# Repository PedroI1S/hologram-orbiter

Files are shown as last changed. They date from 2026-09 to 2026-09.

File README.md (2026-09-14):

# Hologram Orbiter

Display por persistência de visão com três painéis de LEDs. Ponto de projeto:
raio médio 100 mm, 1800 RPM, 29 LEDs por painel e 180 colunas angulares.
A cinemática prevê 90 passagens por segundo; desempenho óptico ainda depende de firmware e ensaio.

**Versão vigente: v3.0, revisão local 3.0.5 de 14/09/2026.**

## Estado

**Não liberado para girar nem para a fabricação definitiva dos painéis.**
A revisão corrigiu a memória de flexão, as contas de partida e energia, os
procedimentos de instrumentação, a parametrização das folgas e as falhas do build.
O buck e suas guias foram recuados radialmente 1,2 mm para eliminar a colisão
com a aranha; o novo teste verifica os envelopes contra a malha final.

A revisão 3.0.5 remove a saliência dos braços dentro da baia e desobstrui
as três entradas de fios. Os critérios geométricos passam a verificar
também essas regiões na malha final.

A seção do painel tem Iyy = **589,8846 mm⁴**, abaixo dos 910 usados antes.
O modelo uniforme dá **3,83–7,74 mm** de deflexão com 44,5 g; no teto de aceite
45 g, chega a **7,83 mm** e ~29,1 MPa. Esses resultados corrigem a aritmética,
mas exigem fechar a transferência de carga, as propriedades FDM e a fluência.

Os relatórios automáticos são a referência da execução atual:

- [Aceitação geométrica](Hologram_Orbiter_v3_0/reports/ACEITACAO.md).
- [Validação e valores atuais](Hologram_Orbiter_v3_0/reports/RELATORIO_VALIDACAO.md).
- [Cálculos reproduzíveis](Hologram_Orbiter_v3_0/reports/FISICA.json).
- [Revisão completa](revisoes/2026-09-08-REVISAO-COMPLETA.md) e [correções aplicadas](revisoes/2026-09-08-CORRECOES-APLICADAS.md).

Aprovação geométrica não substitui os bloqueadores físicos. Massas de catálogo,
chicotes, bateria, ferragens e contrapesos devem ser reconciliados na pesagem real;
o subtotal CAD não comprova a margem até 280 g.

## Números de projeto

| Grandeza | Valor e condição |
|---|---|
| Rotação / velocidade angular | 1800 RPM / 188,496 rad/s |
| Motor / acionamento | A2212 920KV / ESC LittleBee Spring 20A |
| Corrente de regime prevista | 4,95 A de fase; ~16,63 W / 2,38 A na fonte de 7 V, com eficiência ESC assumida de 95% |
| Temperatura prevista | ~46,4 °C, sob as hipóteses térmicas; limite de aceite <55 °C |
| Partida nominal | rampa de RPM ≥12 s; ~7,30 A de fase / 4,02 A na fonte; medir aceleração real |
| Esticada a 2000 RPM | ~6,11 A / 56,3 °C; não liberada |
| Carga radial de referência | 158,1 N por painel de 44,5 g; ~159,9 N a 45 g |
| Energia de projeto | ~27,5 J para J=1,55 g·m², hipótese conservadora não medida |
| Painel solto | ~7,9 J e 18,9 m/s na referência de 44,5 g / r=100 mm |
| Desbalanceamento de referência | 8,4 g·mm usando 252 g; recalcular com a massa final e medir em dois planos |

## Documentos

| Uso | Arquivo |
|---|---|
| Cotas e memória de cálculo | [01 — Especificação](01-ESPECIFICACAO-CAD-v3.0.md) |
| Fases e portões | [02 — Plano de projeto](02-PLANO-DE-PROJETO-v3.0.md) |
| Componentes e instrumentos | [03 — Lista de componentes](03-LISTA-DE-COMPONENTES-v3.0.md) |
| Critérios físicos de aceite | [04 — Plano de ensaios](04-PLANO-DE-ENSAIOS-v3.0.md) |
| Eletrônica e firmware planejado | [05 — Esquema elétrico](05-ESQUEMA-ELETRICO-v3.0.md) |
| O que ainda falta | [06 — Pendências](06-PENDENCIAS-ABERTAS-v3.0.md) |
| Medições e premissas | [07 — Glossário](07-GLOSSARIO-E-PREMISSAS.md) |
| CAD, STL e montagem | [Pacote CAD](Hologram_Orbiter_v3_0/README.md) |

Parâmetros do CAD governam cotas, a especificação governa requisitos e o plano
de ensaios governa aceite físico. Divergências devem ser corrigidas; não se deve
escolher o valor que favorece a aprovação. O legado permanece arquivado e as
revisões históricas descrevem os resultados da data indicada.

Sentido de giro: anti-horário visto de cima; bordo de ataque em +y local.
Balança de 0,01 g, contenção e operação remota são requisitos do ensaio.

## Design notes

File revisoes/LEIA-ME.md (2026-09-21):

# Revisões

Revisões independentes do pacote v3.0, arquivadas por data. Cada uma é um
registro do estado do projeto num dia, com o que foi verificado e como.
Propostas datadas que aguardam decisão também ficam aqui, sob a mesma regra.

**Estes documentos não mandam em cota nem em requisito.** A hierarquia de
autoridade do [`../README.md`](../README.md) continua valendo: o arquivo de
parâmetros do CAD manda em cota, a especificação em requisito, o plano de
ensaios em critério de aceite e o glossário no que foi medido. Uma revisão
aponta divergências; quem as fecha são aqueles arquivos.

O que **falta** está sempre em
[`../06-PENDENCIAS-ABERTAS-v3.0.md`](../06-PENDENCIAS-ABERTAS-v3.0.md), não
aqui.

## Conteúdo

| Arquivo | Escopo | Estado |
|---|---|---|
| [`2026-09-21-PROPOSTA-SPI-QUAD.md`](2026-09-21-PROPOSTA-SPI-QUAD.md) | dados das três fitas: cadeia do 05 ou SPI quad, com ensaio de bancada | proposta, não adotada; decisão na 06 C10 |
| [`2026-09-14-CORRECAO-RAIZES-E-FIACAO.md`](2026-09-14-CORRECAO-RAIZES-E-FIACAO.md) | saliências internas e entradas de fios da aranha, revisão CAD 3.0.5 | corrigidas; sondagem da malha e regressão com os defeitos antigos |
| [`2026-09-03-REVISAO-DAS-RATIFICACOES.md`](2026-09-03-REVISAO-DAS-RATIFICACOES.md) | pacote na revisão de CAD 3.0.3, depois das ratificações B'3, C2 e C9 | aplicada; o que sobrou está na §7 |

A revisão independente anterior, de 03/09/2026, circulou como documento 08
solto e foi incorporada à lista de pendências, com a tabela de disposição dos
30 achados no fim daquele arquivo. Ela não está aqui.

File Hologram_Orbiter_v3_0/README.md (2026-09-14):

# Hologram Orbiter v3.0 — pacote CAD, revisão 3.0.5

**PROVISÓRIO — operação e fabricação definitiva dos painéis não liberadas.**
Revisão local de 14/09/2026. Os cupons continuam úteis para calibração; lote
estrutural depende de fechar seção resistente, transferência de carga, ABS FDM,
fluência, massas/chicotes reais e os bloqueadores do plano de ensaios.

A seção da lâmina é integrada desde os parâmetros e conferida em três cortes
na malha. A folga radial usa a carga do teto de 45 g, com deflexão estimada
máxima de 7,83 mm. Nenhuma alteração de perfil estrutural foi adotada sem validação.
O buck permanece a 140°; o envelope e as guias recuaram 1,2 mm radialmente,
com wall_gap=1,5 mm, para livrar a raiz da aranha.

As raízes dos braços começam em r=39 mm, sem a saliência interna na baia.
O corte de entrada dos fios começa em x local=37 mm e atravessa toda a parede.
A prévia `aranha_entrada_fios.png` mostra o detalhe corrigido; dois critérios
novos sondam as raízes e as janelas na malha final dos três braços.

## Arquivos

| Uso | Arquivo | Qtd |
|---|---|---:|
| Aranha ABS (com pilares, guia do buck e cerca do capacitor) | `exports/stl/01_aranha_ABS.stl` | 1 |
| Painel LED ABS | `exports/stl/02_painel_LED_ABS_1x.stl` | 3 |
| Três painéis na mesma mesa | `exports/stl/02_painel_LED_ABS_3x_mesma_mesa.stl` | 1 lote |
| Tampa da baia ABS (Ø82) | `exports/stl/03_tampa_baia_ABS.stl` | 1 |
| Base + torre integradas ABS (com 4 abas de grampo) | `exports/stl/04_05_base_torre_ABS_integradas.stl` | 1 |
| Suporte do ímã ABS (parte fixa, dois parafusos) | `exports/stl/06_suporte_ima_ABS.stl` | 1 |
| Cupom da junta 11 × 6 | `exports/stl/C01_cupom_junta.stl` | imprimir primeiro |
| Cupom do canal do LED (fatia real de 30 mm do painel) | `exports/stl/C02_cupom_canal_LED.stl` | imprimir primeiro |
| Chapa do motor (referência, NÃO imprimir) | `exports/stl/R01_suporte_motor_aluminio_NAO_IMPRIMIR.stl` | — |
| Chapa do motor **e disco da arruela do eixo** para corte 1:1 | `fabricacao/R01_suporte_motor_60x60_aluminio_2mm.dxf` / `.svg` | alumínio 2 mm |
| Montagem editável (com envelopes da eletrônica da baia) | `exports/fonte/Hologram_Orbiter_v3_0.blend` | — |
| Renders de inspeção; `montagem_baia.png` mostra o layout da baia | `exports/preview/*.png` | — |
| Parâmetros (fonte de verdade) | `CAD/parameters.json` | — |
| Gerador | `CAD/generate.py` | Blender 5.x |
| Sondagem de malha por raios (gerador e validador) | `CAD/probe.py` | NumPy |
| Critérios de aceitação (§9), medidos na malha | `reports/ACEITACAO.md` | automático |
| Relatório geométrico | `reports/geometry_report.json` | automático |
| Validação independente dos STL (topologia + enrolamento) | `reports/stl_validation.json` | automático |
| Relatório de validação | `reports/RELATORIO_VALIDACAO.md` | — |

A tampa do cilindro de contenção (peça 07) saiu do pacote: o invólucro está
fora de escopo (06-PENDENCIAS B7, confirmado em 03/09). `containment_cap.enabled = true` a devolve.

## Como regenerar e verificar

Requer Blender 5.x e Python 3 com NumPy. Na raiz deste pacote:

```sh
./scripts/build.sh
python3 -m unittest discover -s tests -v
python3 -m unittest discover -s scripts/tests -v
blender -b --python-exit-code 1 --python tests/blender_bay_entries.py
```

O build usa staging, propaga erros Python/critério e valida o inventário completo
de nove STLs (dez se a tampa de contenção for habilitada). Só publica depois de
verificar geração, malhas, corte e renders. Falhas preservam os artefatos anteriores.
`reports/build_manifest.json` registra hashes de parâmetros, código e artefatos.

`./scripts/build.sh --no-render` omite todas as prévias e remove as antigas do
pacote publicado, para não misturar revisões. Use `--parameters caminho.json`
para uma configuração alternativa, ou `BLENDER=/caminho/blender`.
As folgas do socket e do cupom são derivadas pela função `CAD/parameters.py` da
espiga e de `quality.joint_xy_clearance_each_side` / `joint_bottom_clearance`.

## Resultados e montagem

[RELATORIO_VALIDACAO.md](reports/RELATORIO_VALIDACAO.md) é gerado na execução;
[ACEITACAO.md](reports/ACEITACAO.md) detalha os critérios e [FISICA.json](reports/FISICA.json)
separa cálculo geométrico, cargas aproximadas e premissas não validadas.
Consulte os relatórios para massas e contrapesos atuais: o subtotal nominal
inclui o Hall, mas os chicotes de seis condutores ainda precisam ser reconciliados
com ferragens reais. A aprovação do subtotal não é aceite da massa final.

A porca do eixo deve ser apertada antes de instalar a bateria e fechar a tampa.
Use [FIACAO_E_MONTAGEM.md](docs/FIACAO_E_MONTAGEM.md),
[GUIA_IMPRESSAO.md](docs/GUIA_IMPRESSAO.md) e
[MEDICOES_DE_ENTRADA.md](docs/MEDICOES_DE_ENTRADA.md).

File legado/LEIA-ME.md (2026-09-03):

# Legado — versões v2.0 e v2.1

**Estes documentos estão arquivados e não devem ser usados como referência.**
A versão corrente é a **v3.0**; comece pelo [`../README.md`](../README.md).

Uma auditoria independente (01/09/2026) encontrou 24 não conformidades na
v2.1, incluindo:

- força centrífuga publicada **71× menor** que a real (2,26 N contra 161,7 N);
- caso térmico que **reprovava com os próprios dados** do documento;
- ensaio de amortecimento errado por **3×**, que aprovava peças fora de spec;
- massa de coxim publicada **10× maior** que a geométrica;
- limite de corrente de 5,8 A **sem derivação** — a planilha que o gerava se perdeu;
- referências a **8 arquivos que nunca existiram** neste diretório.

O registro completo, com o recálculo de cada grandeza, está em
[`00-AUDITORIA-E-INTEGRACAO-v2.1.md`](00-AUDITORIA-E-INTEGRACAO-v2.1.md),
arquivado aqui em 03/09/2026: a memória de cálculo vigente é o §10 da
especificação v3.0, e o que a auditoria ainda tem de útil é o histórico das
decisões. Os números dela sobre contenção, datum e coxim foram substituídos.

## Conteúdo

| Arquivo | O que era |
|---|---|
| `00-AUDITORIA-E-INTEGRACAO-v2.1.md` | auditoria da v2.1 e a decisão que gerou a v3.0 (r = 100 mm @ 1800 RPM); histórico |
| `README-v2.1.md` | índice da v2.1 — a maior parte dos números está errada |
| `Plano-de-Projeto-v2.1.md` | plano de fases; §2.3 tem força centrífuga 2× baixa |
| `Especificacao-CAD-v2.1.md` | especificação das 10 peças a r = 130 mm |
| `Revisao-Tecnica-e-Ajustes.md` | método dos bloqueadores — a estrutura era boa |
| `GUIA-Impressao-Coxim-TPU-v2.1.md` | procedimento TPU com três erros graves |
| `Hologram_Orbiter_v2_1/` e `.zip` | pacote CAD da v2.1 (gerador, STL, relatórios), inalterado |

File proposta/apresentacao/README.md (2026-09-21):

# Apresentação Hologram Orbiter

Abra `apresentacao.html` no navegador. A pasta é independente de servidor e internet: fontes, imagens, estilos e scripts são locais. Para compartilhar a versão animada, envie a pasta inteira.

## Controles

- **F** ou **Apresentar**: entra ou sai do modo apresentação.
- **Setas**, **Page Up / Page Down**, **Espaço**: navegam durante a apresentação.
- **Home / End**: primeiro ou último slide. **Esc**: sai.
- **M** ou **Pausar animações**: pausa e retoma o movimento.
- Clique à esquerda para voltar ou à direita para avançar. No celular, deslize horizontalmente durante a apresentação.
- Mova o ponteiro para a parte inferior para mostrar os controles. Eles também aparecem ao receber foco pelo teclado.
- No slide **A imagem é escrita no ar, uma coluna por vez**, acompanhe os LEDs no instante atual, o rastro das colunas e a imagem formada. Arraste **Varredura por painel** para explorar de 0° a 120°. **Pausar sequência** interrompe a progressão e **Reiniciar** volta ao início. As setas do teclado ajustam o controle que estiver em foco.
- No slide **O rotor desloca o ar e sofre arrasto**, ajuste a **rotação** e o **raio** para observar o movimento dos três painéis, a imagem dos LEDs e a esteira de ar. As setas do teclado ajustam o controle que estiver em foco.
- **Ar e esteira** e **Imagem dos LEDs** mostram ou ocultam as camadas da animação. **Ver gráfico** alterna para o gráfico original de corrente versus raio. **Restaurar 1800 rpm / 100 mm** volta ao ponto de operação da proposta.

A preferência de movimento reduzido do sistema é respeitada. As entradas são automáticas e não acrescentam etapas à navegação. A varredura é uma ilustração em velocidade reduzida, não uma simulação da percepção visual nem um vídeo do protótipo funcionando.

A animação de arrasto também usa movimento desacelerado. As partículas representam o ar deslocado pelos painéis e uma vista superior mostra a força oposta ao movimento. O escoamento é ilustrativo, sem cálculo de CFD. Os indicadores usam `v = 2πrn/60`, `f = 3n/60` e `P/P₀ = (n/1800)³(r/100)³`, com `n` em rpm e `r` em mm (convertido para metros no cálculo da velocidade). A potência é relativa ao ponto de 1800 rpm e 100 mm, mantendo área e coeficiente de arrasto fixos. As previsões dependem de validação em bancada.

## Arquivos

- `apresentacao.html`: roteiro principal, reduzido de 18 para 11 slides.
- `apresentacao.css`: ajustes visuais, transições e regras de impressão.
- `apresentacao.js`: navegação e animação dos diagramas existentes.
- `orbiter-renderer.js`: desenho em perspectiva do rotor do slide 2, seguindo as formas e cores do slide 4.
- `principio.js`: sequência em três Canvas para mostrar o instante de escrita, o acúmulo das colunas e a imagem formada, com controle de progresso.
- `arrasto.js`: cena em Canvas com rotor, LEDs e escoamento ilustrativo, além dos controles do ponto de operação.
- `apresentacao.pdf`: versão estática dos 11 slides, incluindo um quadro da nova cena de arrasto. As animações e os controles funcionam no HTML.
- `apresentacao-completa-original.html` e `.pdf`: versão anterior preservada, com cálculos e explicações detalhadas. O botão **Detalhes técnicos** abre o HTML original.

As sete imagens PNG utilizadas são cópias dos renders do Blender em `Hologram_Orbiter_v3_0/exports/preview`. Os renders mostram o CAD, não peças já fabricadas. As estimativas e os critérios vêm da apresentação e da proposta originais. O estado provisório do CAD vem do README da revisão 3.0.5, de 14/09/2026.

Para atualizar o PDF após editar o HTML:

```sh
python3 gera_pdf.py
```

Também é possível imprimir pelo navegador, com gráficos de fundo habilitados. A impressão mostra todo o conteúdo, inclusive quando aberta a partir do modo apresentação.

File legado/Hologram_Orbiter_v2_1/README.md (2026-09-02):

# Hologram Orbiter v2.1 — projeto CAD para fabricação

Este diretório contém o CAD paramétrico, os STL em milímetros, a montagem
Blender, cupons de calibração e os relatórios de validação do Hologram Orbiter
v2.1. A fonte de requisitos é
[`../Especificacao-CAD-v2.1.md`](../Especificacao-CAD-v2.1.md).

## Estado da liberação

**PROVISÓRIO — NÃO LIBERADO PARA GIRO A 1800 RPM.**

As malhas foram geradas e validadas para impressão, mas a especificação deixa
interfaces físicas sem medição e contém conflitos de segurança. É aceitável
imprimir os dois cupons de calibração. Não é aceitável operar o rotor em alta
rotação até fechar os itens de [`docs/PENDENCIAS_CRITICAS.md`](docs/PENDENCIAS_CRITICAS.md).

## Arquivos principais

| Uso | Arquivo | Quantidade |
|---|---|---:|
| Aranha ABS | [`exports/stl/01_aranha_ABS.stl`](exports/stl/01_aranha_ABS.stl) | 1 |
| Painel ABS | [`exports/stl/02_painel_LED_ABS_1x.stl`](exports/stl/02_painel_LED_ABS_1x.stl) | 3 |
| Três painéis na mesma mesa | [`exports/stl/02_painel_LED_ABS_3x_mesma_mesa.stl`](exports/stl/02_painel_LED_ABS_3x_mesma_mesa.stl) | 1 lote |
| Tampa ABS | [`exports/stl/03_tampa_baia_ABS.stl`](exports/stl/03_tampa_baia_ABS.stl) | 1 |
| Base + torre integradas ABS | [`exports/stl/04_05_base_torre_ABS_integradas.stl`](exports/stl/04_05_base_torre_ABS_integradas.stl) | 1 |
| Coxim TPU opcional | [`exports/stl/07_coxim_TPU95A_4x_mesma_mesa.stl`](exports/stl/07_coxim_TPU95A_4x_mesma_mesa.stl) | 4 |
| Cupom da junta | [`exports/stl/C01_cupom_junta_11x6.stl`](exports/stl/C01_cupom_junta_11x6.stl) | testar primeiro |
| Cupom do canal LED | [`exports/stl/C02_cupom_canal_LED_13x1p8.stl`](exports/stl/C02_cupom_canal_LED_13x1p8.stl) | testar primeiro |
| Montagem editável | [`exports/fonte/Hologram_Orbiter_v2_1.blend`](exports/fonte/Hologram_Orbiter_v2_1.blend) | — |
| Parâmetros | [`CAD/parameters.json`](CAD/parameters.json) | fonte de verdade |
| Gerador | [`CAD/generate.py`](CAD/generate.py) | Blender 5.x |

O anel TPU e o suporte de motor possuem STL apenas como **referência**. A
especificação classifica o anel como peça não impressa e exige o suporte em
alumínio de 2 mm; não os substitua por ABS.

## Como regenerar

Requer Blender 5.x e Python 3 com NumPy para a validação independente.

```bash
./scripts/build.sh
```

O comando recria os STL, o `.blend`, a prévia e os relatórios. Para alterar as
interfaces ainda não medidas, edite `CAD/parameters.json`; não edite o STL.

## Resultado geométrico

- Painel: 208 mm de altura; canal 13 × 1,8 mm; socket 11,2 × 6,2 mm; Datum D no
  centro, 104 mm da base.
- Aranha: cubo Ø80 × 6 mm, três braços a 120°, ombro em r=104 mm e espiga até
  r=126 mm.
- Base: footprint Ø300 mm; baia central de 80 mm; topo da torre em Z=154 mm.
- Datum do rotor assumido: Z=188 mm, usando altura provisória de 34 mm entre o
  suporte e o Datum B.
- Todos os STL estão orientados para começar em Z=0 e usam coordenadas em mm.

Consulte [`docs/GUIA_IMPRESSAO.md`](docs/GUIA_IMPRESSAO.md) antes de fatiar e
[`reports/RELATORIO_VALIDACAO.md`](reports/RELATORIO_VALIDACAO.md) para os
resultados dimensionais e de malha.

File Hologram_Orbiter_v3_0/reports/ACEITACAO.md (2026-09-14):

# Critérios de aceitação — Hologram Orbiter v3.0

Verificação automática a partir do modelo (spec §9). Gerado por `CAD/generate.py`.
Valores marcados como medidos vêm de traçado de raios na malha final (`CAD/probe.py`),
não dos parâmetros de entrada.
**CAD provisório: aprovação geométrica não libera giro nem fabricação definitiva dos painéis.**
Consulte `FISICA.json` e os bloqueadores de resistência, fluência, massa e instrumentação.

| Critério | Valor no modelo | Requisito | Resultado | Nota |
|---|---:|---|:---:|---|
| Raio do plano médio do painel | 100.0 | 100 ±0,1 mm | ✅ | medido: ombro da longarina na malha da aranha ([74.0, 74.0, 74.0]) + 26 da face de contato |
| Datum D | 104.0 | 104 ±0,2 mm | ✅ | da malha do painel |
| Δh entre painéis | 0.0 | ≤ ±0,5 mm | ✅ | os três painéis são o mesmo STL |
| Ponta da espiga | 96.0 – 96.0 – 96.0 | 96 ±0,1 mm | ✅ | medido na malha |
| Profundidade do socket | 22.5 | 22.5 ±0,1 mm | ✅ | medido: primeiro material no eixo do socket |
| Parede entre o fundo do socket e a cavidade | 1.5 | ≥ 1,2 mm | ✅ | medido |
| Piso sob o canal do LED | 0.8 | ≥ 0,6 mm (nominal 0.80) | ✅ | medido a meia altura no centro; na borda do canal: 0.8; na junta: 0.8. Ponte de 12.4 mm |
| Terra entre o piso e a parede de 2,0 | 2.8 | ≥ 2,0 mm (parede local 2,8 em 1 mm de cada lado do canal) | ✅ | medido |
| Furos M3 livres em toda a torre | True – True | livres (sem pino de casca invertida) | ✅ | raio ao longo do eixo de cada parafuso: enrolamento 0 em toda a extensão (06-PENDENCIAS A1) |
| Bolso da porca M3 e torre | 2.8 – 2.8 | bolso 2.8 ±0,1 mm; torre sólida de −15,2 a +18, só o socket (z ±3.1) a interrompe | ✅ | medido ao longo do eixo de cada parafuso; vãos: [[[-3.1, 3.1]], [[-3.1, 3.1]]] |
| Parede ao redor do bolso de porca | 1.65 | ≥ 1,5 mm | ✅ | geometria: torre Ø10, hexágono de circunraio 3,35 |
| Casca da carenagem | 0.8 | 0.8 ±0,05 mm | ✅ | medido no flanco plano |
| Parede estrutural nas seções amostradas | 0.8 | ≥ 0.80 mm | ✅ | Amostras: piso do canal, flanco da carenagem, borda do disco, pele da tampa e nervuras; não certifica a espessura mínima global da malha |
| Enrolamento por raios — painel | 0 – 0 | 0 trechos com enrolamento ∉ {0,1} · 0 lâminas < 0,02 mm | ✅ | 18719 raios, passo 1.0 mm |
| Enrolamento por raios — aranha | 0 – 0 | 0 trechos com enrolamento ∉ {0,1} · 0 lâminas < 0,02 mm | ✅ | 16660 raios, passo 1.5 mm |
| Enrolamento por raios — tampa | 0 – 0 | 0 trechos com enrolamento ∉ {0,1} · 0 lâminas < 0,02 mm | ✅ | 7885 raios, passo 1.0 mm |
| Enrolamento por raios — base | 0 – 0 | 0 trechos com enrolamento ∉ {0,1} · 0 lâminas < 0,02 mm | ✅ | 18612 raios, passo 3.0 mm |
| Enrolamento por raios — suporte do ímã | 0 – 0 | 0 trechos com enrolamento ∉ {0,1} · 0 lâminas < 0,02 mm | ✅ | 10195 raios, passo 0.5 mm |
| Furo do cubo livre | True | livre | ✅ | Ø8.0 para eixo medido em Ø8.0 |
| Rebaixo da arruela | 0.0 | 0.0 ±0,1 mm (zero: arruela no topo do cubo) | ✅ | medido; 6.0 mm de cubo sob a arruela |
| Pele sobre os alívios do cubo | 2.0 | ≥ 2,0 mm | ✅ | medido |
| Arruela passa pelo colar Ø8.0 do eixo | 0.5 | furo − colar ≥ 0,3 mm | ✅ | arruela Ø20 × Ø8.5 × 2.0 (aluminio 2 mm, cortada da mesma chapa da R01 (referencia de corte inclui o disco)). Uma arruela M6 (furo 6,4) assentaria no colar e a porca não apertaria o cubo |
| Porca não toca o colar do eixo | 1.0 | topo da arruela ≥ topo do colar + 0,5 mm | ✅ | colar até 1.0 acima do topo do cubo (desenho: ressalto 2 + colar 5); arruela até 2.0 |
| Rosca sobrando acima da porca | 3.0 | ≥ 1 mm | ✅ | eixo de 14 mm acima da campânula (desenho; não medido); na leitura de 12 mm sobrariam 1.0. Porca fina de 3 mm sobre arruela de 2.0, sem rebaixo; trava química no lugar do anel de nylon |
| Trilhos do berço acima da porca | 9.0 | ≥ 5.0 mm (topo da porca) | ✅ |  |
| Fundo da bateria acima da ponta do eixo | 1.0 – 3.0 | ≥ 1,0 mm nas duas leituras do eixo (14 e 12 mm sobre a campânula) | ✅ | piso medido na malha em Z = 9.0; ponta do eixo em +8.0 (leitura de 14) e +6.0 (leitura de 12). Critério novo: o eixo é mais alto que a porca e nenhum critério os comparava |
| Assento da arruela livre acima do cubo | 10.5 | menor raio sólido ≥ 10.3 mm (raio da arruela + 0,3) | ✅ | varredura de 360 raios na espessura da arruela; os trilhos do berço são o material mais interno |
| Bateria cabe na baia sobre a porca | 26.0 | ≤ 29 mm | ✅ | pack de 17 mm sobre trilhos em Z=9 |
| Berço da bateria dentro da baia (meia-diagonal) | 32.26 | ≤ 39 mm | ✅ | abas de topo inclusas |
| Raízes sem saliência dentro da baia | 0 – 0 – 0 | zero raios obstruídos nos três braços | ✅ | Sondagem da faixa central de cada raiz (y ±2 mm), junto à face interna da parede e acima do piso; guias laterais fora da amostra |
| Entradas de fios atravessam a parede da baia | 0 – 0 – 0 | zero raios obstruídos nas três janelas e na transição ao bolso | ✅ | Sondagem da abertura completa e da ligação ao bolso externo, na malha final |
| Layout da baia: envelopes e faixas dos feixes | ok | envelopes dentro da baia, Z ≤ 28.0; piso livre para feixes | ✅ | 4 componentes; pilares em [[21.5, -3.0], [32.5, -3.0], [32.5, 13.0], [21.5, 13.0], [-34.0, -9.25], [-20.0, -9.25], [-20.0, 9.25], [-34.0, 9.25]] |
| Eletrônica sem interseção com a malha final da aranha | 0.0 – 0.0 – 0.0 – 0.0 | ≤ 0.001 mm³ por envelope (tolerância numérica) | ✅ | Inclui raízes dos braços e suportes; módulos reais ainda precisam de medição |
| Seção de flexão confere com cortes da malha | 589.8846 – 589.8846 – 589.8846 | integrais da seção iguais nos parâmetros e em três cortes | ✅ | Verifica o cálculo geométrico; não certifica resistência, fluência ou ABS FDM |
| Eletrônica embarcada (estimada) dentro da folga | 15.0 | ≤ 15 g | ✅ | massas de catálogo, não pesadas; o XL4015 sozinho (~18 g) estouraria |
| Contrapeso planejado do layout | 2.19 – 0.87 | cabe nos alívios (≤ 13.9 g cada) e deixa resíduo ≤ 8.4 g·mm | ✅ | desbalanceamento nominal 63.2 g·mm a 23.2° (admissível 8.4); correção a 203.2° repartida em 2.19 g no alívio de 180°, 0.87 g no alívio de 300°; resíduo 0.15 g·mm. Fontes: eletrônica da baia 74.0 g·mm a 12°; aranha (malha) 12.5 g·mm a 144°; tampa (malha) 9.6 g·mm a 180°; sensor hall nu 5.8 g·mm a 20° |
| Área livre de ventilação do cubo | 475.6 | ≥ 300 mm², sem abrir a baia | ✅ | 3 rasgos de 60° fora da baia (r 41.5–45.0) |
| Área livre de ventilação da base | 1152.0 | ≥ 600 mm², na lateral | ✅ | 8 janelas na parede lateral da baia |
| A × Cd do boss carenado | 237.6 – 316.8 | ≤ 350.0 mm² | ✅ | estimativa por razão de finura, não CFD |
| Subtotal nominal por painel | 42.14 | ≤ 45.00 g | ✅ | Chicote de seis condutores e ferragens reais ainda não reconciliados; não é aceite de massa final |
| Subtotal nominal do rotor | 278.68 | ≤ 280.00 g | ✅ | Inclui Hall e contrapeso; completar orçamento dos chicotes antes do aceite de massa |
| Massa da aranha | 70.88 | ≤ 75 g (alvo) | ✅ | alvo para cubo Ø92 e baia de 29 mm |
| Massa da tampa | 10.12 | ≤ 12 g (alvo) | ✅ | alvo revisto para Ø82 |
| Massa da base + torre | 319.8 | ≤ 330 g (alvo) | ✅ | peça estática; o custo é tempo de impressão |
| Perpendicularidade torre/base | 0.0 | ≤ 1° | ✅ | no CAD é zero; verificar na peça impressa |
| Contato da base | 0.0 | sem balanço; ≤ 0,2 mm em 3 pontos a 120° | ✅ | no CAD é plano; verificar na peça impressa |
| Malhas (arestas não-manifold no gerador) | 0 | 0 | ✅ | validação independente em reports/stl_validation.json |
| Base + brim cabe na mesa | 296.0 – 296.0 | ≤ [300.0, 300.0] mm (X e Y) | ✅ | envelope medido em cada eixo, com o brim configurado |
| Piso da baia íntegro sob os furos da flange | 0.0 – 12.0 | sólido de Z = 0 até a flange inferior (12) | ✅ | 06-PENDENCIAS B3; furos só na flange superior: True |
| Rebaixo da flange livra as cabeças dos M3 do motor | 3.5 – 16.0 | profundidade ≥ 3.3 mm e raio livre ≥ 15.5 mm | ✅ | medido na malha; cabeça Ø5.5 × 3.0 em r = 12.42 (retângulo 16 × 19). Os M4 em PCD 40 ficam fora do rebaixo e continuam definindo o assento da chapa |
| Abas de grampo com furo livre | True | livre | ✅ | 4 abas a 90°, furo Ø5 em r = 149 |
| Fita de 201,4 mm cabe no canal | 102.9 | ≤ 104 mm (topo do painel) | ✅ | batente em Z=-98.5 por causa do bolso de fios |
| Suporte do ímã com dois pontos de fixação | 2 | ≥ 2 parafusos | ✅ | 06-PENDENCIAS B4; arco a 4.6 mm da campânula |
| Folga do suporte do ímã à campânula | 4.6 | ≥ 2 mm | ✅ | campânula medida em Ø28 |
| Canaleta de assento dentro da pista | 2.8 – 2.8 | lábios ≥ 1,2 mm | ✅ | provisão (invólucro fora de escopo): canaleta r 132.8–137.2 |
| Cilindro encomendado cabe na canaleta | 0.2 – 0.2 | folga ≥ 0 nos dois lados | ✅ | Ø int 266, parede 4, contra canaleta de 4.4 |
| Folga radial rotor → cilindro encomendado | 21.17 | ≥ 10 mm após deflexão | ✅ | informativo: raio dinâmico 111.8 contra Ø int 266 |
| Folga vertical topo do rotor → borda do cilindro encomendado | 17.0 | ≥ 10 mm | ✅ | informativo: cilindro de 305 mm apoiado em Z=5 |

**Resultado:** 58 de 58 critérios atendidos.

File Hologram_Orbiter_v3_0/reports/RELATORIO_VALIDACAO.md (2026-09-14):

# Relatório de validação CAD — v3.0.5

Gerado por CAD/generate.py na mesma execução de geometry_report.json e FISICA.json.
**PROVISÓRIO: não libera operação nem fabricação definitiva dos painéis.**

## Geometria

Critérios: 58/58. Ver ACEITACAO.md para requisitos e cobertura.
A validação dos STL exportados aparece em stl_validation.json; o build só publica se ela também passar.

| Peça | Massa CAD (g) | Dimensões (mm) | Triângulos |
|---|---:|---|---:|
| spider | 70.88 | [148.763, 171.777, 35.0] | 10988 |
| panel_each | 31.94 | [30.0, 50.0, 208.0] | 3988 |
| lid | 10.12 | [82.0, 82.0, 5.0] | 6552 |
| base_tower | 319.8 | [280.0, 280.0, 154.0] | 8080 |
| magnet_bracket | 1.81 | [23.386, 41.554, 21.5] | 1726 |
| joint_coupon | 10.07 | [58.0, 24.0, 12.0] | 60 |
| led_coupon | 3.53 | [8.0, 30.0, 30.0] | 154 |
| motor_plate_reference_aluminium | 18.38 | [60.0, 60.0, 2.0] | 3536 |

## Física

Iyy da seção = 589.8846 mm⁴; centroide x = -0.53095 mm.
As integrais são comparadas com três cortes da malha. Propriedades FDM e engaste não certificados.

| Massa usada | L (mm) | E (MPa) | Deflexão (mm) | Tensão máxima (MPa) |
|---:|---:|---:|---:|---:|
| 44.5 | 86.0 | 2300.0 | 3.832 | 21.724 |
| 44.5 | 86.0 | 2000.0 | 4.407 | 21.724 |
| 44.5 | 99.0 | 2000.0 | 7.739 | 28.788 |
| 45.0 | 86.0 | 2300.0 | 3.875 | 21.968 |
| 45.0 | 86.0 | 2000.0 | 4.457 | 21.968 |
| 45.0 | 99.0 | 2000.0 | 7.826 | 29.111 |

Folga radial calculada com o teto de massa: 21.17 mm.
Carga uniforme simplificada: não representa certificação de resistência ou fluência.

## Acionamento

Regime: 4.95 A de fase, 16.63 W / 2.38 A na fonte de 7 V.
Rampa nominal >= 12 s de RPM; conferir aceleração e corrente reais no bloqueador D.
- 8 s: 8.47 A de fase / 4.98 A na fonte.
- 12 s: 7.30 A de fase / 4.02 A na fonte.

## Montagem e orçamento nominal

Interseções da eletrônica com aranha: [{'component': 'interface', 'intersection_mm3': 0.0}, {'component': 'esp32c3', 'intersection_mm3': 0.0}, {'component': 'buck', 'intersection_mm3': 0.0}, {'component': 'capacitor', 'intersection_mm3': 0.0}].
Contrapesos nominais: [{'pocket_center_deg': 180.0, 'mass_g': 2.19, 'radius_mm': 33.0}, {'pocket_center_deg': 300.0, 'mass_g': 0.87, 'radius_mm': 33.0}].
Subtotal do rotor: 278.68 g, limite 280 g.
Ferragens por painel4g permanecem estimativa anterior. Chicote de seis condutores precisa ser pesado e reconciliado com estas ferragens antes de declarar massa total; o subtotal nominal nao garante o teto280g.

| Referência global | Z (mm) |
|---|---:|
| Datum B, topo do cubo | 186.0 |
| Trilhos/fundo da bateria | 195.0 |
| Topo da bateria | 212.0 |
| Ponta do eixo | 194.0 |

## Ainda não verificado

Resistência e fluência do painel impresso, caminho de carga, massas/chicotes reais, instrumento de fase e térmica, dropout do buck, polaridade/entreferro reais e contenção. Ver 06-PENDENCIAS-ABERTAS-v3.0.md.

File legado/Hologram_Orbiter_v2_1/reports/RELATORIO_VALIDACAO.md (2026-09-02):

# Relatório de validação CAD — Hologram Orbiter v2.1

Data da geração: 01/09/2026. Unidade de exportação: milímetro.

## Resultado

Todos os 11 STL exportados passaram na validação independente:

- zero triângulos degenerados;
- zero arestas abertas ou com incidência diferente de duas faces;
- volume orientado positivo;
- base de impressão normalizada em Z=0;
- envelopes principais coerentes com o modelo paramétrico.

O resultado detalhado e legível por máquina está em
[`stl_validation.json`](stl_validation.json). O relatório de volumes e
parâmetros está em [`geometry_report.json`](geometry_report.json).

## Dimensões e massas geométricas

As massas abaixo usam volume CAD × densidade nominal (ABS 1,04 g/cm³; TPU
1,20 g/cm³). Para peças espessas, o valor real depende do fatiamento; para
paredes finas, a estimativa fica mais próxima da peça impressa.

| Peça | Envelope exportado (mm) | Massa geométrica |
|---|---:|---:|
| Aranha | 193,76 × 223,74 × 30,95 | 57,55 g |
| Painel, cada | 208 × 30 × 30¹ | 26,89 g |
| Tampa | 70 × 70 × 5 | 7,58 g |
| Base + torre | 300 × 300 × 154 | 306,42 g |
| Coxim TPU, cada | 16 × 16 × 8 | 1,85 g |
| Anel TPU de referência | 300 × 300 × 10 | 109,15 g |

¹ O painel está deitado no STL: 208 mm ficam em X. Os 30 mm em Z incluem a
profundidade radial do boss; a lâmina continua com espessura máxima de 8 mm. O
boss tem extensão vertical de 36 mm no sistema de montagem, contida dentro dos
208 mm de altura total do painel.

## Checagens contra a especificação

| Requisito | Resultado CAD | Situação |
|---|---:|---|
| Painel impresso ≤35 g | 26,89 g | passa para a peça nua |
| Datum D | 104 mm da base | passa nominalmente |
| Lâmina | 208 × 30 × 8 mm | passa |
| Canal LED | 13 × 1,8 mm | passa nominalmente; medir fita |
| Espiga | 11 × 6 × 22 mm | passa |
| Socket | 11,2 × 6,2 × 22,5 mm útil | passa; 0,1 mm/lado e 0,5 mm no fundo |
| Ombro da longarina | r=104 mm | passa |
| Plano médio do painel | r=130 mm | passa na montagem |
| Base | Ø300 mm | passa |
| Baia central | Ø100 × 80 mm | passa |
| Torre | Ø30, parede 4 mm | passa |
| Topo da torre | Z=154 mm | fecha Z=188 com motor provisório de 34 mm |
| Coxim | Ø16 × 8, furo Ø3,2 | passa |

## Itens reprovados ou não verificáveis

- Massa geométrica do rotor impresso (aranha + 3 painéis + tampa): **145,80 g**,
  acima do total publicado de 120 g. O valor real com infill pode cair, mas o
  próprio orçamento de máximos da especificação soma mais de 120 g; é necessária
  uma revisão formal do requisito e pesagem física.
- Proteção de 260 mm: insuficiente para o envelope vertical calculado até
  Z=295 mm quando iniciada no solo.
- Folga radial após a deflexão prevista: somente 2,5 mm até o anel Ø280 interno.
- Furação do motor, fita LED, bateria e altura do conjunto não foram medidas.
- FEA, análise modal, fadiga e contenção de falha não foram executadas.

## Conclusão de liberação

Os arquivos estão tecnicamente válidos como malhas de prototipagem e como base
paramétrica para a revisão. Estão liberados os **cupons de calibração**. As peças
grandes podem ser impressas para verificação dimensional estática, assumindo o
custo do retrabalho, mas o conjunto não está liberado para operar a 1800 RPM.

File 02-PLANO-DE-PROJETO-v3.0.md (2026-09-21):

# Plano de projeto — Hologram Orbiter v3.0

**Atualização local 08/09, revisão 3.0.4:** fabricação definitiva dos painéis e giro dependem de fechar a revisão estrutural e qualificar a instrumentação do plano 04. O CAD é provisório.

**Atualização de 21/09:** a ESP32 da base substitui o Arduino, e o plano ganhou a imagem pelo celular: página hospedada na ESP32 da base e imagem transmitida por rádio ao rotor (esquema 05 §9).

---

## 1. O que o projeto entrega

Um display volumétrico por persistência de visão: três painéis de LEDs
endereçáveis girando a 1800 RPM formam uma imagem cilíndrica de **Ø208 × 201 mm**,
com **29 × 180 pixels** e taxa de imagem de **90 Hz**.

Entregáveis finais:

1. protótipo mecânico balanceado, operando de forma estável e contida;
2. cadeia óptica funcional — fita, controlador, índice angular, imagem de teste;
3. os cinco bloqueadores aprovados com evidência registrada;
4. documentação de operação, com memória de cálculo rastreável;
5. imagem enviada pelo celular: página hospedada na ESP32 da base e
   transmitida por rádio ao ESP32-C3 do rotor (esquema 05 §9).

## 2. Estado atual

| Bloco | Situação |
|---|---|
| Ponto de operação | ✅ congelado — r = 100 mm, 1800 RPM, 90 Hz |
| Cadeia de acionamento | ✅ A2212 920KV · ESC LittleBee Spring 20A · fonte de bancada · ESP32 da base (DevKit 30 pinos) |
| Cadeia óptica | ✅ HD107S 144/m · ESP32-C3 · A3144 nu no rotor |
| Imagem pelo celular | 🔄 planejada no esquema 05 §9; hardware em mãos, firmware a fazer |
| Especificação CAD | ✅ escrita, corrigida e alinhada ao CAD em 03/09 |
| Modelo CAD | ⚠️ rev. local 3.0.4: 56 critérios geométricos; resistência e ensaios continuam pendentes |
| Compras | 🔄 motor, ESC, fita, ESP32-C3, bateria LiFe e hall em mãos; faltam buck, shifter, ímã, ferragens, chapa e filamento |
| Medições | ⚠️ colar e ponta do eixo a partir da face de apoio; massa real da eletrônica |
| Isolamento de vibração | ⚠️ montagem rígida; o ensaio de impacto decide |

## 3. Como este plano difere do anterior

A versão anterior perseguia 90 Hz subindo a rotação com o raio fixo em 130 mm.
Como a potência aerodinâmica escala com **ω³r³**, isso exigia 9,76 A e levava o
motor a 101 °C — inviável com o A2212 920KV que temos, cujo limite prático é
térmico, em torno de 5,5 A.

Os mesmos 90 Hz, na **mesma** 1800 RPM, com o raio em 100 mm, custam **4,95 A e
46 °C** pela estimativa de arrasto do CAD (4,44 A e 43 °C no melhor caso). O
alvo estava certo desde o começo; a alavanca estava errada.

Três mudanças de método que vêm junto:

- **Nenhum número sem origem.** Toda grandeza é rastreável até um datasheet, uma
  medição ou uma linha de cálculo publicada. A versão anterior perdeu a planilha
  que gerava seus números e ficou sem como auditá-los.
- **Critérios medíveis.** Os bloqueadores são lidos em instrumentos que existem
  na bancada, não em grandezas que exigiriam instrumentação que não temos.
- **Pendência declarada em vez de valor inventado.** O que não foi medido fica
  marcado como não medido.

---

## 4. Fases

### Fase 0 — Projeto e aquisição · em curso

| Atividade | Saída |
|---|---|
| Modelagem CAD v3.0 | gerador paramétrico, STLs, montagem, relatórios |
| Verificação do CAD contra os critérios da especificação | relatório de conformidade |
| Compras do caminho crítico | bateria, ESP32-C3, regulador, hall, ímã, fio, filamento |
| Layout da baia de eletrônica | esboço verificado no CAD (envelope, interferências, contrapeso); pesar as peças reais |

**Portão G0:** CAD entregue e aprovado nos critérios do §9 da especificação;
cupons impressos e conferidos com a fita real.

### Fase 1 — Fabricação

| Atividade | Saída |
|---|---|
| Cupons C01 e C02 | folgas da junta e do canal validadas |
| Lote dos 3 painéis, mesma mesa e mesmo lote | 3 painéis medidos e pesados |
| Aranha, tampa, suporte do ímã | peças conferidas |
| Base + torre | perpendicularidade e planeza verificadas |
| Corte e furação da chapa de alumínio | suporte do motor |

**Portão G1:** massa ≤ 45 g por painel · **Δm ≤ 0,084 g** · Datum D 104 ±0,2 mm ·
raio 100 ±0,1 mm · Δh ≤ ±0,5 mm. Peça fora de tolerância é reimpressa, não ajustada.

### Fase 2 — Montagem mecânica

| Atividade | Saída |
|---|---|
| Motor na chapa, chapa na torre | conjunto fixo alinhado |
| Aranha no eixo, com a arruela Ø20 × Ø8,5 em alumínio e a porca M6 fina com trava química | rotor acoplado |
| Painéis nas longarinas, porcas planas com trava química | rotor completo, sem LEDs |
| Balanceamento estático | painéis casados em massa |
| Contenção de ensaio montada | caixa fechada, chapa ou tela; policarbonato se for usar o rádio (esquema 05 §9.4) |
| Firmware da rampa na ESP32 da base: armação, rampa ≥ 12 s, teto do pulso, watchdog e botões (esquema 05 §8.2) | sinal do ESC conferido na bancada, sem motor |

**Portão G2:** rotor montado, girando à mão sem rocamento perceptível,
contenção de ensaio montada, rampa da ESP32 da base conferida na bancada.

> **Pesar os painéis é necessário, não suficiente.** Δm ≤ 0,084 g casa as
> *massas*, não os *momentos*: dois painéis de massa idêntica com o CG em raios
> diferentes — infill que caiu mais no boss num deles e mais na lâmina no outro
> — continuam desbalanceando. 0,5 mm de diferença de CG em 42 g já vale
> 21 g·mm, duas vezes e meia o admissível. A pesagem tria os casos grosseiros;
> quem fecha a conta é o bloqueador C.

### Fase 3 — Bloqueadores de rotação

Ensaios A (potência), B (térmica), C (vibração) e D (partida). Detalhe em
[`04-PLANO-DE-ENSAIOS-v3.0.md`](04-PLANO-DE-ENSAIOS-v3.0.md).

**Portão G3:** P_entrada ≤ 20 W · T_motor < 55 °C · vibração ≤ 0,20 g a 30 Hz ·
10 de 10 partidas. **Sem LEDs até aqui.**

### Fase 4 — Integração óptica

| Atividade | Saída |
|---|---|
| Fita nos painéis, fiação pela carenagem e longarina | cadeia elétrica do rotor |
| ESP32-C3, regulador, bateria na baia | eletrônica de bordo |
| Sensor hall no rotor, ímã no suporte fixo | referência de fase |
| Firmware: SPI, índice, mapeamento de colunas | imagem de teste na tela |
| Enlace ESP-NOW: a base transmite, o rotor troca a imagem no índice | imagem enviada da base aparece na tela |
| Rebalanceamento com a eletrônica montada | rotor final balanceado |

**Portão G4:** imagem de teste estável a 1800 RPM, taxa de dados confirmada.

### Fase 5 — Validação visual e demonstração

Ensaio E, ajuste de brilho e contraste, documentação de operação.

Imagem pelo celular: página na ESP32 da base (QR code, desenho, galeria, fila e
aprovação) e ensaio do enlace de imagem do plano 04, antes de abrir ao público.

**Portão G5:** jitter imperceptível em sacada, operação contínua estável e,
depois do ensaio do enlace, imagem enviada pelo celular sem tremor.

---

## 5. Cronograma

Semanas relativas à entrega do CAD. Deslocam junto com ela.

| Semana | Fase | Marco |
|---|---|---|
| 1 | 0 | CAD regenerado · compras disparadas |
| 2 | 1 | cupons · lote dos painéis · aranha e tampa |
| 3 | 1 | base e torre (impressão longa) · chapa cortada |
| 4 | 2 | montagem · balanceamento estático · rampa na bancada · **G2** |
| 5 | 3 | ensaios A e B |
| 6 | 3 | ensaios C e D · **G3** |
| 7 | 4 | fiação, eletrônica, firmware, enlace de rádio |
| 8 | 4 | imagem de teste · rebalanceamento · **G4** |
| 9 | 5 | ensaio E · ajustes · **G5** |
| 10 | 5 | página na base · ensaio do enlace · demonstração com o celular |

**Caminho crítico:** a impressão da base leva 12–18 h numa única peça e não pode
ser paralelizada. Comece cedo, e só depois que os painéis passarem em G1 — se o
raio precisar mudar, a base muda junto.

**Folga real:** as compras (semana 1) e a impressão (semanas 2–3) correm em
paralelo. Se a bateria atrasar, as Fases 1 a 3 seguem sem ela: nada em G3 depende
da eletrônica de bordo.

---

## 6. Riscos

| Risco | Prob. | Impacto | Sinal antecipado | Mitigação |
|---|---|---|---|---|
| Arrasto acima do estimado | média | alto | P_entrada > 20 W em G3 | carenagem do boss; recuo para 1500 RPM |
| Motor aquece além do previsto | média | alto | curva térmica sem estabilizar | ventilação da baia; é o fator que decide |
| Partida sensorless falha | **média** | médio | travamento na rampa | rampa de 12 s; duty alto; ESC sensored |
| Δm entre painéis fora | média | médio | pesagem em G1 | massa adesiva; reimpressão |
| Eletrônica mais pesada que o catálogo | média | médio | pesagem das peças reais (massa completa e chicotes ainda não reconciliados) | mini560 em vez de XL4015; polyfuse em vez de porta-fusível; alívios mais fundos |
| Vibração acima do limite | baixa | médio | FFT em G3 | balanceamento em dois planos |
| Fluência do painel em operação | **média** | alto | ponta afastando entre medições | limitar tempo contínuo; medir deflexão a quente |
| Falha estrutural do painel | baixa | **crítico** | trinca na inspeção | SF 2,5 — inspecionar entre patamares |
| Ressonância da parte fixa | média | alto | pico fora de 1× na varredura | ensaio de impacto antes de montar o motor; grampear a base |
| Rádio atrasa as colunas do rotor | média | médio | tremor acima de 46 µs no ensaio do enlace | rotor só escuta; colunas acima do rádio; janelas de rádio |
| Rádio fraco no rotor | média | baixo | perda de pacotes no ensaio de alcance | 8,5 dBm na Super Mini; contenção de policarbonato; base mais perto |
| Página pública alcança o motor | baixa | **crítico** | qualquer rota de motor no servidor | página sem comando de motor; teto do pulso; watchdog; corte físico da fonte |

**O risco que mais mudou de posição:** a partida. Com inércia 100× a de uma
hélice e ESC sensorless, é agora um bloqueador próprio, não um detalhe de
configuração.

**O risco menos confortável — e mal nomeado até aqui.** Versões anteriores deste
plano falavam em "fadiga, 108 mil ciclos por hora". Está errado: **a carga
centrífuga é estática**. Num rotor de eixo vertical, nem a força centrífuga nem o
peso mudam de direção em relação ao painel — nenhum dos dois cicla a 30 Hz. Os
ciclos de fadiga reais são as **partidas e paradas**, que serão dezenas.

A **fluência** permanece um bloqueador: a seção revisada eleva a tensão do modelo uniforme a ~29,1 MPa no teto de 45 g. Não há lei medida deste ABS FDM que sustente a previsão anterior de perda de metade do módulo em 100 h. Primeiro fechar resistência e transferência de carga; depois executar o ensaio de crescimento sob carga do bloqueador B, sem presumir vida útil por extrapolação.

O que **de fato** cicla a 30 Hz é a vibração de desbalanceamento, e é por isso
que o Bloqueador C importa.

---

## 7. Definição de sucesso

O projeto é bem-sucedido quando, simultaneamente:

- a imagem se forma a 90 Hz, estável e sem jitter perceptível em sacada;
- P_entrada ≤ 20 W e o motor estabiliza abaixo de 55 °C em regime contínuo;
- a vibração a 30 Hz fica em ≤ 0,20 g, sem crescimento;
- o rotor parte de forma confiável, 10 vezes em 10;
- a imagem enviada pelo celular aparece sem tremor, e nada na página alcança o
  motor;
- toda cota e todo número do projeto são rastreáveis até um datasheet, uma
  medição ou uma linha de cálculo publicada.

Se algum critério não for atendido, a resposta correta não é forçar a operação.
É reduzir rotação, trocar a peça crítica ou revisar a geometria — cada caminho
já está escrito no plano de ensaios.

---

## 8. Documentos

| Documento | Papel |
|---|---|
| [`README.md`](README.md) | ponto de entrada e estado |
| [`01-ESPECIFICACAO-CAD-v3.0.md`](01-ESPECIFICACAO-CAD-v3.0.md) | **manda em toda cota** |
| [`02-PLANO-DE-PROJETO-v3.0.md`](02-PLANO-DE-PROJETO-v3.0.md) | fases, portões, riscos |
| [`03-LISTA-DE-COMPONENTES-v3.0.md`](03-LISTA-DE-COMPONENTES-v3.0.md) | o que comprar e por quê |
| [`04-PLANO-DE-ENSAIOS-v3.0.md`](04-PLANO-DE-ENSAIOS-v3.0.md) | bloqueadores e critérios |
| [`05-ESQUEMA-ELETRICO-v3.0.md`](05-ESQUEMA-ELETRICO-v3.0.md) | eletrônica do rotor e da base, e o enlace de imagem |
| [`06-PENDENCIAS-ABERTAS-v3.0.md`](06-PENDENCIAS-ABERTAS-v3.0.md) | o que ainda falta |
| [`07-GLOSSARIO-E-PREMISSAS.md`](07-GLOSSARIO-E-PREMISSAS.md) | vocabulário e origem de cada número |
| [`legado/`](legado/LEIA-ME.md) | v2.0, v2.1 e a auditoria que as reprovou — histórico, não referência |

## Condições atualizadas para os portões

Antes de G1: fechar a seção resistente e a transferência de carga/FDM/fluência; cupons de calibração não liberam o lote de painéis. Em G3 usar lastro representativo da distribuição final e referência angular fixa sincronizada, pois o Hall embarcado só entra em G4. Qualificar a medição térmica sem cabos em superfícies girantes e o método de dois planos antes de registrar aprovação. Repetir os ensaios aplicáveis em G4 com bateria, chicotes, sensores e retenções finais; reconciliar a massa completa contra 280 g. Antes de abrir a página ao público: ensaio do enlace de imagem (plano 04) e contenção fechada que deixe passar o rádio.

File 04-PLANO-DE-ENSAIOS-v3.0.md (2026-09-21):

# Plano de ensaios — Hologram Orbiter v3.0

Cinco bloqueadores. **Revisados em 08/09/2026; nenhum ensaio físico consta como
aprovado.** A instrumentação térmica, a referência angular e a identificação
em dois planos precisam ser fechadas antes dos ensaios correspondentes. As
correções digitais não liberam a estrutura para girar; resolver antes as
pendências mecânicas da revisão completa. Em 21/09/2026 entrou o ensaio do
enlace de imagem, que não é bloqueador de rotação.

> **Por que este plano é diferente do da v2.1.** O critério antigo era
> `I ≤ 5,8 A`, um número cuja derivação estava numa planilha que se perdeu, e que
> além disso exige instrumentação apropriada à corrente comutada de fase. A
> leitura na fonte é realizável, mas não comprova diretamente corrente de fase;
> a conversão usada abaixo é uma estimativa com hipóteses explícitas.

---

## Bloqueador A — potência e arrasto

**O que se está de fato verificando:** se o arrasto aerodinâmico real bate com o
estimado. É a maior incerteza do projeto e a entrada de todo o caso térmico.

**Método.** Rotor completo montado e balanceado, sem LEDs acesos. Subir em
patamares de 600, 1000, 1400 e 1800 RPM, 2 min em cada. Ler **tensão e corrente
na fonte de bancada** e calcular a potência de entrada.

| Corrente de fase | P entrada | I na fonte a 7 V | T motor prevista | |
|---:|---:|---:|---:|---|
| 3,0 A | 9,0 W | 1,29 A | 34 °C | |
| 4,0 A | 12,7 W | 1,81 A | 40 °C | |
| 4,44 A | 14,47 W | **2,07 A** | 43 °C | melhor caso (Cd do boss 0,20) |
| **4,95 A** | **16,63 W** | **2,38 A** | **46 °C** | ← **ponto de projeto** (Cd do boss 0,35) |
| 5,0 A | 16,85 W | 2,41 A | 47 °C | |
| 5,5 A | 19,1 W | 2,73 A | 51 °C | limite aceitável |
| 6,0 A | 21,47 W | 3,07 A | 55,3 °C | previsão acima do limite térmico |
| 8,0 A | 32,1 W | 4,59 A | 77 °C | parar imediatamente |

**Critério de aceite:** P_entrada **≤ 20 W** a 1800 RPM, em regime estável.

Tabela derivada de `P_entrada = (Kt·ω·I + 0,221·I² + 0,7)/0,95`, com
Kt=0,0103797 N·m/A, ω=188,496 rad/s e eficiência de ESC assumida de 95%.
Temperatura prevista: `25 + 3,5·(0,221·I² + 0,7)` °C. R e Rth continuam
hipóteses; medir potência não identifica sozinho torque ou perdas do motor.

**Limiar de aborto:** P_entrada > 30 W, ou T_motor **≥ 55 °C**, o que vier
primeiro. Este limite de potência é de regime; o pico de partida tem o critério
próprio do bloqueador D.

**Se falhar:**
1. Verificar o **sentido de giro** — invertido, o arrasto sobe muito. Bordo de
   ataque deve apontar para o sentido do movimento.
2. Revisar a carenagem do boss: era 54% do arrasto no projeto sem carenagem.
3. Reduzir para 1500 RPM (75 Hz) e reavaliar.
4. Só então considerar reduzir raio ou altura do painel.

---

## Bloqueador B — térmica em regime contínuo

**Instrumentação — pendente.** A campânula do A2212 gira. **Não prender nela
um termopar com cabo ligado a leitor estacionário.** Para medir a superfície
girante, selecionar medição sem contato com emissividade, tamanho do ponto e
reflexões controlados, validada contra referência de contato com o motor parado,
ou um sensor embarcado com retenção e transmissão de dados qualificadas.
Termopar na chapa/assento fixo mede esse ponto, não automaticamente o motor;
só usar como substituto após estabelecer uma correlação térmica conservadora.
Registrar o ponto medido e a incerteza. Sem método qualificado, B permanece aberto.

**Método, após fechar a instrumentação.** Operar 10 min contínuos a 1800 RPM.
Registrar T × tempo a cada 30 s. Termopares estacionários podem medir a estrutura
ABS, a baia da base e a chapa. Na decisão de aceite/aborto, considerar a
incerteza da medição no sentido conservador.

**Critérios de aceite:**

| Ponto | Limite |
|---|---|
| Temperatura do motor pelo método qualificado | **< 55 °C** e curva estabilizando, sem subida contínua |
| Estrutura ABS próxima ao motor | < 60 °C |
| Bateria no rotor | < 45 °C — **só quando houver bateria embarcada**; ver nota |
| **Deflexão da ponta do painel** | **crescimento < 0,5 mm após 1 h a temperatura** |

**Limiar de aborto:** motor **≥ 55 °C**, ABS próximo ao motor ≥ 60 °C ou
bateria ≥ 45 °C, quando embarcada. Falha da medição também interrompe o ensaio.

**Sobre a linha da bateria.** O bloqueador B roda na fase 3, e a fase 3 é
explicitamente *sem LEDs e sem eletrônica de bordo* (portão G3). Nessa passagem
não há bateria no rotor para medir. A linha vale como critério **na repetição do
ensaio B em G4**, com a eletrônica montada — que é quando a bateria de fato gira
em torno do eixo, dentro de uma baia fechada. A bateria exige sensor embarcado
calibrado com telemetria ou registro local, cuja massa, retenção e montagem
ainda precisam ser definidas. Medir depois de parar não demonstra o pico em
operação. Em G3, registrar "não aplicável"; em G4, manter B aberto até existir
medição realizável e evidência da temperatura.

**Meça a ponta do painel, não só a temperatura.** O ABS flui sob carga
sustentada a quente. A revisão da seção elevou a tensão prevista para
~21,7–28,8 MPa (44,5 g), chegando a ~29,1 MPa com o teto de 45 g no modelo simplificado; a lei de fluência do material impresso
não foi medida. Antes do ensaio de 1 h é necessário liberar o caso estrutural
revisto. Marque a posição radial da ponta de um painel com o rotor parado, opere
1 h em regime, pare e meça de novo. Crescimento acima de 0,5 mm indica que a
fluência vai comer a folga radial antes do fim do semestre.

**A curva importa tanto quanto o pico.** Se a temperatura ainda estiver subindo
aos 10 min, o ensaio não passou — repita com 20 min ou aceite que o regime
permanente está acima do limite.

**Se falhar:** o caminho é ventilação, não redução de rotação. A análise mostra
que a diferença entre 68 °C e 99 °C no pior caso de arrasto é **só o coeficiente
de troca térmica**. Verificar se as janelas laterais da baia estão desobstruídas
e se há caminho de ar passando pelo motor. Só depois reduzir RPM.

---

## Bloqueador C — vibração e balanceamento

**O que mudou:** a v2.1 media ζ do coxim. Como o isolador está indefinido e a
montagem inicial é rígida, o que importa agora é a **vibração residual da
estrutura**, que é consequência direta do balanceamento.

**Método, em duas partes.**

**C0 — ensaio de impacto, antes de energizar o motor.** Com a base impressa na
bancada, MPU6050 colado junto à torre, dar um toque seco no topo da torre e
registrar o decaimento. FFT dá a primeira frequência natural da parte fixa.

**Ensaie com massa na ponta, ou o ensaio não mede nada.** A torre nua, batida
sem massa no topo, ressoa em centenas de hertz: o gatilho de 45 Hz abaixo nunca
dispararia e o ensaio passaria sempre. Fixe no eixo uma **massa fictícia de
~280 g** na altura do plano dos painéis (um disco de aço na porca M6 serve), ou
monte o rotor real parado, e só então bata na torre.

O tubo Ø30 × 4 × 150 dá **k ≈ 50 N/mm**. Com a massa concentrada **no topo do
tubo** isso daria fn ≈ 63 Hz, e é esse o número que os documentos vinham
publicando — mas a massa não está no topo. O CG do conjunto (rotor 279 g +
motor 52 + chapa 18 = **349 g**, e não os 322 g da base, que é outra peça) fica
em Z ≈ 185, **31 mm acima do topo da torre** (Z = 154). Para massa deslocada de
`a` por um trecho rígido:

```
k_eff = k / (1 + 3a/L + 3a²/L²) = 50 / (1 + 0,62 + 0,13) ≈ 29 N/mm
fn    ≈ (1/2π)·√(29 000 / 0,349) ≈ 46 Hz
```

e isso ainda ignora a inércia de rotação do rotor de 208 mm, a flexibilidade da
flange, da chapa e dos rolamentos do motor (todas abaixam) e o efeito
giroscópico a 1800 RPM (sobe o modo direto). **O número honesto é ≈ 45 Hz** — em
cima do próprio limiar de reforço, com transmissibilidade a 30 Hz de ~1,7 a 1,9
em vez dos 1,3 que 63 Hz prometia. Meça antes de acreditar em qualquer um dos
dois.

O que a conta também não cobre é o **balanço da base sobre a mesa**: ela apoia, e
é presa só pelas quatro abas de grampo nos cantos do anel. Medir grampeada e
solta. Se a medição der **fn < 45 Hz**, reforce antes de montar o motor: piso
100 % sólido num raio de 40 mm em torno da torre e 4 a 8 gussets da torre para a
parede da baia, que hoje não trabalha.

**C1 — varredura em rotação.** Acelerômetro na base, junto à torre. Amostrar a 500 Hz
e **varrer de 600 a 1800 RPM em degraus de 200**, registrando amplitude × rotação.
Medir só a 1800 não distingue ressonância de desbalanceamento: desbalanceamento
cresce com ω², ressonância aparece como pico numa rotação específica. FFT em cada
patamar, lendo **1× e 2× a rotação efetiva** (30 e 60 Hz somente a 1800 RPM).
Definir escala, filtro antialias, janela de FFT e calibração da amplitude;
os limites abaixo são amplitudes de pico, não valores RMS.

**Critérios de aceite:**

| Grandeza | Limite |
|---|---|
| Pico a 30 Hz | ≤ 0,20 g |
| Pico a 60 Hz | ≤ 0,10 g |
| Crescimento em 10 min | nenhum |
| Desbalanceamento residual | ≤ **8,4 g·mm** |

**Balanceamento, em duas etapas antes deste ensaio:**

1. **Estático, na bancada** — pesar os três painéis numa balança de **0,01 g** e
   casar em **≤ 0,084 g**. Se não casar, corrigir com massa adesiva antes de
   montar.
2. **Dinâmico em dois planos — instrumentação pendente.** Instalar uma
   referência **1 pulso/volta fixa**, observando uma marca no rotor e registrada
   na mesma base de tempo dos sinais de vibração. O Hall embarcado de G4 e uma
   leitura numérica de RPM não fornecem essa referência em G3. Usar duas
   respostas complexas independentes, por exemplo dois pontos de medição em
   alturas distintas da estrutura fixa; comprovar independência, não presumir
   que dois eixos do mesmo MPU bastam.

   Fazer três ensaios separados, na mesma rotação e condição de montagem:
   baseline sem massa de teste; massa conhecida somente no plano 1, medindo
   ambos os canais; retirar essa massa e testar somente o plano 2, novamente
   medindo ambos. Para cada plano, registrar massa, raio e fase. Montar a matriz
   complexa 2 × 2 de coeficientes de influência `A_ij = (V_ij − V_i0)/U_teste_j`
   e resolver `A·U_correcao = −V_0`. Se a matriz for singular ou mal condicionada,
   mudar os pontos/condições de medição; não emitir dois contrapesos de uma só
   resposta. Aplicar a correção e repetir uma medição independente do resíduo.

   Registrar o resíduo estimado em cada plano e a incerteza. Usar como teto
   conservador provisório `|U_1| + |U_2| ≤ 8,4 g·mm`, recalculado para a massa
   real conforme a spec §2.1; isso não substitui um limite qualificado de binário
   nem a avaliação dos modos. Vibração baixa sozinha não comprova esse U.
   [Método de balanceamento, Brüel & Kjær](https://www.bksv.com/media/doc/17-227.pdf).

   No CAD: plano 1 nos alívios inferiores do cubo (r 17–36); plano 2 nos copos
   da tampa (r = 34). A correção nominal de catálogo de 2,19 g a 180° e 0,86 g
   a 300° é apenas a compensação inicial do layout e pode mudar ao regenerar.
   Em r = 34, 0,1 g produz 3,4 g·mm; a balança de 0,01 g resolve incrementos
   de 0,34 g·mm nesse raio. Verificar retenção e capacidade dos alojamentos reais.

**Se falhar:** repetir o balanceamento em dois planos. Se persistir, procurar
excentricidade da bateria (50 g deslocados 1 mm já dão 50 g·mm, seis vezes o
admissível) ou empeno de painel.

---

## Bloqueador D — partida

**Bloqueador novo.** O rotor tem **1,55 g·m²**, cerca de **100 vezes** a inércia
de uma hélice 1045. ESCs sensorless são sintonizados para hélice, e partida com
inércia alta é o modo de falha clássico: o motor perde sincronismo e trava.

**Método.** Com o rotor completo, rampa nominal configurada em **≥ 12 s**, executar 10
partidas consecutivas do repouso até 1800 RPM.

Confirmar a curva de RPM: uma rampa linear de pulso servo não garante uma
rampa linear de velocidade. Com J=0,00155 kg·m² e arrasto de 51,4 mN·m, a
aceleração linear em 12 s exige 24,35 mN·m e prevê **7,30 A de fase**,
~28,17 W / **4,02 A na fonte de 7 V**, usando η_ESC=95%. Em 8 s seriam
**8,47 A de fase / 4,98 A na fonte**, fora do limite. O mínimo matemático para
8 A é ~9,23 s, sem margem; não é a rampa nominal.

**Critérios de aceite:**
- 10 de 10 partidas bem-sucedidas, sem travamento nem ruído de dessincronismo;
- pico de corrente na fonte durante a rampa ≤ **4,6 A a 7 V** (32,1 W / 7 V, a
  mesma linha da tabela do bloqueador A; estimativa equivalente a 8,0 A
  de fase nesse modelo, não uma medição de corrente de fase);
- nenhum evento de proteção do ESC.

**Se falhar:**
1. Alongar a rampa além dos 12 s nominais, medir a aceleração e recalcular
   `I_fase=(J·ω/t + 0,0514)/0,0103797`. Manter o teto de 4,6 A na fonte a 7 V.
2. Reduzir a potência de partida nas configurações do ESC.
3. Ajustar a fonte para 6–7 V, o que faz o ESC operar em duty mais alto e melhora
   a resolução de comutação em baixa rotação.
4. **Desabilitar o "Low RPM power protect"** do BLHeli_S. A 1800 RPM estamos a
   26 % da rotação a vazio, exatamente o regime que essa proteção limita; o
   manual indica desabilitá-la para motores de baixo kv em tensão baixa. Em
   troca, aumenta o risco de perda de sincronismo — ajuste de bancada.
5. **Desabilitar o "Brake on stop".** O BLHeli_S freia com regeneração, e uma
   fonte de bancada não afunda corrente: frear 27,6 J empurra o barramento para
   cima.
6. Se nada resolver, o caminho é um ESC sensored ou um controlador FOC.

---

## Bloqueador E — qualidade visual

**Método.** Ambiente escuro, imagem de teste com padrões de alto contraste:
grade fina, texto pequeno e bordas verticais. Observar a 1, 2 e 3 m de distância,
parado e com movimento rápido dos olhos (sacada). Registrar com celular a 240 fps.

**Critérios de aceite:**
- imagem estável, sem jitter perceptível em sacada;
- as três varreduras coincidem — nada de imagem "tripla" ou borrada;
- sem cintilação perceptível em visão periférica.

**Se falhar, o diagnóstico vem antes da correção:**

| Sintoma | Causa provável | Correção |
|---|---|---|
| Imagem tripla ou fantasma | Δh ou raio diferentes entre painéis | remedir Datum D e o raio; reimprimir o painel fora |
| Deslocamento angular entre varreduras | atraso de atualização serial ou folga na junta | medir temporização/compensação por LED; conferir junta e fase mecânica |
| Borda vertical serrilhada | jitter de fase do sensor de índice | verificar entreferro e histerese do hall |
| Tremor só quando chega imagem nova | interrupções do rádio no rotor | janelas de rádio (esquema 05 §9.4) |
| Imagem "respirando" ou cisalhada | rotação instável entre voltas | **o BLHeli_S não tem governor** — ver abaixo |
| Cintilação periférica | 90 Hz insuficiente para o brilho usado | reduzir brilho; 2000 RPM não liberados pelo cálculo atual |

---

**2000 RPM não estão liberados.** No mesmo arrasto de projeto, a previsão é
`4,95·(2000/1800)² = 6,11 A` e **56,3 °C**, acima do limite de 55 °C.
Uma mudança de rotação exige novo caso mecânico/elétrico e repetição dos
bloqueadores aplicáveis; passar a 1800 RPM não autoriza essa extensão.

**Sobre a imagem "respirando".** O sensor de índice zera a fase a cada volta, então
o erro não acumula — mas dentro de cada volta ele cresce proporcionalmente à
variação de rotação desde a volta anterior. Para manter o desvio abaixo de 1/4 de
coluna, a rotação precisa ser estável dentro de **~0,14 %** de uma volta para a
outra. A inércia de 1,55 g·m² ajuda muito nisso.

Se falhar aqui, **não procure ajuste mecânico e não procure o modo governor**: o
BLHeli_S não tem malha fechada de rotação. Ou se aceita a variação, ou se troca
o firmware por um com telemetria de RPM.

---

## Enlace de imagem — rádio da base ao rotor

**O que se verifica:** se o rádio do rotor atrapalha a varredura e se a imagem
chega inteira com o rotor girando e a tampa fechada. O projeto está no esquema
05 §9. Não é bloqueador de rotação; é condição para abrir a página ao público.

**Parte 1 — tremor, na bancada, com o rotor parado.** ESP32-C3 do rotor com o
firmware final e o índice simulado por um pulso a 30 Hz no GPIO 3, vindo da
ESP32 da base ou de um gerador de funções. Analisador lógico na primeira borda
de CLK de cada quadro. Medir o atraso de cada coluna em relação ao instante
previsto por 10 min sem rádio e por 10 min recebendo uma imagem de 180 × 29 a
cada 5 s.

**Critério:** pior atraso com rádio abaixo de **46 µs** (1/4 de coluna) e
nenhuma coluna perdida. Se falhar, usar janelas de rádio (esquema 05 §9.4) e
repetir.

**Parte 2 — alcance, girando.** Rotor final a 1800 RPM, na contenção de
policarbonato e com a tampa fechada; ESP32 da base na posição de uso. Enviar 100
imagens seguidas.

**Critério:** as 100 chegam com o CRC certo, com reenvio se preciso.

**Parte 3 — visual.** Repetir o Bloqueador E com imagens chegando pelo rádio.

---

## Sequência e portões

```
G0  CAD entregue e verificado contra os critérios do §9 da especificação
     └─ cupons impressos, junta e canal conferidos com a fita real

G1  Lote impresso e verificado
     └─ massa ≤ 45 g por painel · Δm ≤ 0,084 g · Datum D 104 ±0,2 · raio 100 ±0,1

G2  Montagem mecânica e balanceamento estático
     └─ rotor montado sem LEDs · painéis casados em massa

G3  Bloqueadores A, B, C, D   ← ensaios de rotação, sem LEDs
     └─ instrumentação qualificada · P ≤ 20 W · T < 55 °C · C em dois planos · 10/10 partidas

G4  Integração óptica
     └─ fita, ESP32, sensor de índice, imagem de teste; repetir A–D no rotor final

G5  Bloqueador E e demonstração
     └─ imagem pelo celular só depois do ensaio do enlace de imagem
```

**Nada de LEDs antes de G3.** Os ensaios de rotação são os de maior risco físico;
adicionar eletrônica de bordo antes deles só aumenta o que se perde numa falha.
Usar lastro retido que represente massas, posições e inércia dos itens ausentes,
inclusive fitas e chicotes; registrar a configuração de cada ensaio. Lastro
central de massa total igual não reproduz automaticamente o rotor final.
Após integrar os componentes reais em G4, repetir balanceamento e A–D; incluir
a medição da bateria em B e a qualificação de corrente/temperatura do buck.

---

## Regras de segurança em ensaio de rotação

Não são formalidade. O rotor guarda **27,6 J** e um painel solto sai a
**18,9 m/s** com 7,9 J.

- **Nunca girar sem contenção integral.** Caixa fechada, chapa ou tela de aço em
  torno do rotor. Não há exceção para "só um teste rápido". Com o enlace de
  imagem (esquema 05 §9), a contenção precisa deixar passar 2,4 GHz:
  policarbonato, não tela de aço.
- **Operação remota.** Ninguém no plano do rotor durante a subida de rotação.
  Com público, ele fica fora da contenção, e a página do celular nunca comanda
  o motor (esquema 05 §8.2).
- **Parada de emergência** ao alcance, cortando a fonte. Ela corta a
  alimentação, **não para o rotor**: com *brake on stop* desabilitado (decisão
  correta para a fonte de bancada) o rotor entra em roda livre e o arrasto cai
  com ω². A constante de tempo é `I·ω/T = 1,55e−3 × 188,5 / 0,046 ≈ 6 s` e a
  rotação decai como `ω₀/(1 + t/τ)`: metade em 6 s, um décimo em ~1 min, com os
  27,6 J ainda dentro da contenção nos primeiros segundos.
- **Ninguém abre a contenção antes de o rotor parar — no mínimo 90 s após o
  corte, e só com o rotor visivelmente imóvel.** Se for preciso frear de fato,
  use um resistor de descarga no barramento do ESC; nunca a fonte.
- **Subir em patamares** com inspeção entre eles. Nunca ir direto a 1800.
- Após qualquer reimpressão ou remontagem, **refazer o balanceamento**.
- **Grampear a base à bancada** pelas abas externas do anel (quatro, nos
  cantos; três bastam) antes de qualquer ensaio de rotação. Ela tem 321 g e
  caminha se o contato for ruim.
- Óculos de proteção, sempre.

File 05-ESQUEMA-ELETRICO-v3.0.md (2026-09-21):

# Esquema elétrico — Hologram Orbiter v3.0

Duas cadeias elétricas independentes, que **não se tocam**. Não há anel coletor.

**No rotor** (§1 a §7): bateria, controlador, sensor de índice e as três fitas,
tudo girando a 1800 RPM.

**Na parte fixa** (§8): fonte de bancada, ESC, motor e a ESP32 da base, que gera
o sinal de acelerador. Mais o ímã, que dá ao rotor a referência de fase.

**Entre as duas** (§9): um enlace de rádio. A ESP32 da base hospeda a página em
que o público desenha ou escolhe uma imagem e a transmite por ESP-NOW ao
ESP32-C3 do rotor. Nenhum fio cruza, e o rádio só leva imagem, nunca comando de
motor.

**Revisado em 08/09/2026. Em 21/09/2026: pull-downs do 74AHCT125, ESP32 na base
no lugar do Arduino e enlace de imagem (§9).** Este documento especifica um circuito e firmware
planejados. Não há firmware implementado neste pacote nem ensaio elétrico
aprovado. Buck, chicotes, medição térmica e temporização continuam pendentes.

Diagrama visual, com a parte fixa e o enlace de imagem: **https://claude.ai/artifact/V2a7t33rNmrC91UtgS54Zp**

---

## 1. Topologia

```
Bateria 2S ─ chave ─ fusível 7,5 A ─ buck 5,0 V ─┬─ C bulk 1000 µF
                                                  │
                          ┌───────────────────────┼──────────────┐
                          │                       │              │
                     ESP32-C3                74AHCT125       A3144 (5 V)
                    (lógica 3,3 V) ──CLK/DATA──▶ (→ 5 V) ──┐   coletor aberto
                          ▲                                 │        │
                          └────────── índice ───────────────┼────────┘
                                                            │   pull-up 10k → 3V3
                                                            ▼
                          Painel 1 ─ Painel 2 ─ Painel 3    (cadeia de 87 LEDs)
                             ▲          ▲          ▲
                             └──────────┴──────────┘  5 V e GND em estrela
```

**Potência em estrela, dados em cadeia.** Cada painel recebe 5 V e GND direto do
cubo (1,74 A cada em branco pleno). Os dados percorrem um único barramento SPI
com os 87 LEDs em série.

## 2. As duas armadilhas

Nenhuma aparece na montagem. As duas aparecem quando a imagem não acende.

### 2.1 O A3144 não funciona a 3,3 V

Ele opera de **4,5 a 24 V**. Alimentado pelo 3V3 do ESP32, não comuta.

Como a saída é **coletor aberto**, a solução é limpa: sensor em **5 V** e
**pull-up de 10 kΩ no 3V3**. Quem define o nível alto é o pull-up, então o sinal
oscila de 0 a 3,3 V e a entrada do ESP32-C3 — que **não** tolera 5 V — fica
protegida.

> Pull-up para 5 V queima a porta. Sem pull-up nenhum, não há sinal.

> **Use o A3144 nu, não a placa HW-477.** O módulo tem pull-up próprio para o seu
> VCC: alimentado em 5 V, a saída vai a 5 V e queima a entrada do ESP32-C3. E a
> placa de 18 × 15 mm pesa 1,5–2,5 g, que a r = 29 mm valem 43 a 72 g·mm contra
> os **8,4** admissíveis. Dessoldado, o TO-92 pesa 0,2 g e cabe no bolso do CAD.

### 2.2 3,3 V não aciona a fita com segurança

A HD107S em 5 V pede `V_IH ≥ 0,7 × VDD = 3,5 V`; o ESP32-C3 entrega 3,3 V. A
15,4 Mbit/s, com fio correndo dentro do rotor, isso não é margem.

**Adotado:** `74AHCT125` nos dois sinais. A família AHCT tem entrada TTL
(V_IH 2,0 V) e saída de 5 V — é exatamente o conversor 3,3 → 5 V.

Ligar os dois `/OE` usados ao GND, fixar as entradas dos canais não usados em
nível definido e colocar 100 nF cerâmico junto a VCC/GND do CI. A pinagem depende
do encapsulamento comprado. O capacitor bulk não substitui esse desacoplamento.
[Datasheet Texas Instruments](https://www.ti.com/lit/ds/symlink/sn74ahct125.pdf).

**Pull-down de 10 kΩ ao GND nas entradas de CLK e DATA do CI.** No reset, o
GPIO 4 e o GPIO 6 ficam só como entrada, sem pull-up nem pull-down, e continuam
assim até o firmware configurar o SPI. Com a entrada do buffer flutuando, a
saída pode oscilar, e a fita pode receber lixo e acender no boot, antes de
existir o limite de corrente do firmware (§5). No pior caso, em branco pleno,
são 5,2 A. O pull-down segura CLK e DATA em nível baixo até o SPI assumir e
custa 0,33 mA por pino quando o ESP32-C3 puxa 3,3 V.
[Datasheet ESP32-C3, tabela de pinos](https://documentation.espressif.com/esp32-c3_datasheet_en.html).

**Não usar buck em 4,5 V como substituto garantido do buffer.** O limiar de
~3,15 V continua acima do V_OH mínimo de 0,8 × VDD = 2,64 V especificado para o
ESP32-C3. O regulador da Super Mini e a fita reais também precisam ser
identificados. [Datasheet ESP32-C3](https://documentation.espressif.com/esp32-c3_datasheet_en.html).

## 3. Pinos do ESP32-C3

| Sinal | Pino | Vai para | Nota |
|---|---|---|---|
| SPI CLK | GPIO 4 | 74AHCT125 entrada A | 20 MHz solicitados, 180 colunas, DMA; medir clock efetivo (§5); pull-down 10 kΩ (§2.2) |
| SPI MOSI | GPIO 6 | 74AHCT125 entrada B | dados da cadeia; pull-down 10 kΩ (§2.2) |
| ÍNDICE | GPIO 3 | saída do A3144 | interrupção na borda de descida |
| V_BAT | GPIO 0 (ADC) | divisor **150k / 47k** + **100 nF ao GND no pino** | 1,72 V a 7,2 V (LiFe cheia) · corte em 1,38 V (= 5,8 V) |
| 5V | 5V | trilho do buck | — |
| 3V3 | 3V3 | pull-up do hall | regulador da placa |
| GND | GND | trilho comum | estrela no cubo |

A numeração é sugestão. O que importa: CLK e MOSI saindo do periférico SPI, e o
índice num pino com interrupção.

## 4. Chicote por longarina

O sulco tem 4,4 × 3 mm. A topologia exige **seis condutores**: duas vias de
potência, duas de entrada e duas de retorno da cadeia. A estimativa de duas
camadas (3,7 × 2,35 mm) depende dos diâmetros **com isolação**, ainda não medidos.
Conferir a rota inteira com o chicote real, incluindo janelas, diafragmas,
dobras e saída da fita; não declarar cabimento só pela bitola do cobre.

| Condutor | Bitola | Corrente | Cor | P1 | P2 | P3 |
|---|---|---:|---|:--:|:--:|---|
| +5 V | AWG 24 | 1,74 A | vermelho | ✓ | ✓ | ✓ |
| GND | AWG 24 | 1,74 A | preto | ✓ | ✓ | ✓ |
| CLK entrada | AWG 28 | — | amarelo | ✓ | ✓ | ✓ |
| DATA entrada | AWG 28 | — | verde | ✓ | ✓ | ✓ |
| CLK retorno | AWG 28 | — | amarelo/branco | ✓ | ✓ | montado, sem uso |
| DATA retorno | AWG 28 | — | verde/branco | ✓ | ✓ | montado, sem uso |

> **Monte o chicote idêntico nos três painéis.** A cadeia só precisa de retorno
> em dois, mas **meio grama de fio a menos no painel 3 gera 50 g·mm de
> desbalanceamento**, contra os 8,4 admissíveis — seis vezes o limite. Deixe o
> retorno do painel 3 montado e desconectado: custa 0,5 g de peso morto e poupa
> uma correção de 0,55 g.

O retorno sai da ponta superior da fita, desce pela cavidade aberta do painel —
passando pelos vãos dos diafragmas — e volta pelo bolso de fios da ponta
inferior. **Prenda com kapton a cada 50 mm:** fio solto dentro do painel oscila
e desbalanceia.

## 5. Orçamento de energia e temporização

Base de cálculo, **a confirmar na fita real**: 87 × 60 mA × 5 V = **26,1 W**
de LEDs em branco pleno. Seja `f` a fração efetiva dessa corrente RGB, incluindo
conteúdo e ajuste de brilho. 15% e 30% são cenários, não perfis medidos.
O ESP32-C3 acrescenta **0,3 W na saída do buck**, uma única vez. Com eficiência
assumida de 87,5%: `P_bat = (26,1·f + 0,3)/0,875`, `I_bat = P_bat/6,6` e
`t = 0,8/I_bat` horas. Consumo adicional do Hall/buffer, rádio, perdas dos fios,
capacidade útil e eficiência ao longo da descarga devem entrar após medição.

| Cenário | P LEDs | P saída buck (LEDs + ESP) | P bateria | I bateria a 6,6 V | Autonomia teórica |
|---|---:|---:|---:|---:|---:|
| Branco 100%, referência de dimensionamento | 26,10 W | 26,40 W | 30,17 W | 4,57 A | 10,5 min |
| Teto provisório de 80% | 20,88 W | 21,18 W | 24,21 W | 3,67 A | 13,1 min |
| Conteúdo equivalente a 30% | 7,83 W | 8,13 W | 9,29 W | 1,41 A | 34,1 min |
| Conteúdo equivalente a 15% | 3,915 W | 4,215 W | 4,82 W | 0,730 A | 65,8 min |

**Buck de exatamente 5 A não cobre branco pleno:** são 5,22 A de LEDs mais
0,06 A do ESP, antes dos demais consumos. Até qualificar o componente real,
especificar limite de corrente global: **f ≤ 80% e corrente total medida na
saída ≤ 4,25 A**, valendo o menor limite. Isso é um teto provisório para ensaio,
não a aprovação de qualquer módulo anunciado como 5 A. Verificar regulação,
ripple e temperatura com a tensão de entrada de 7,2 até 5,8 V e com a carga
máxima autorizada. O firmware deverá implementar a limitação antes do primeiro
acendimento; ainda não está implementado. Branco pleno exige redimensionamento
ou comprovação de capacidade contínua superior a 5,28 A. A autonomia útil fica
**pendente de ensaio**; não manter a promessa anterior de 45–50 min.

Um quadro planejado tem `32 + 87 × 32 + 44 = 2860 bits`. A quantidade de bits
de fim deve ser conferida com o lote HD107S real; 44 é a provisão atual da
cadeia. O buffer DMA pode ter 360 bytes alocados/alinhados, com comprimento de
transmissão explicitamente definido; se transmitir os 2880 bits, recalcular.

| RPM × colunas | Quadros/s | Taxa útil | Janela por quadro | Transmissão a 20 MHz | Folga antes do overhead |
|---|---:|---:|---:|---:|---:|
| 1800 × 180 | 5400 | 15,444 Mbit/s | 185,19 µs | 143,00 µs | 42,19 µs |
| 2000 × 180, não liberado | 6000 | 17,160 Mbit/s | 166,67 µs | 143,00 µs | 23,67 µs |
| 1800 × 256, experimental | 7680 | 21,965 Mbit/s | 130,21 µs | 143,00 µs | −12,79 µs |

Clock solicitado não é clock garantido: no ESP32-C3, pedir 30 MHz com fonte
de 80 MHz e divisor inteiro resulta normalmente em **26,67 MHz**. Ler a
frequência efetiva e medir no pino. Nesse clock, 2860 bits duram 107,25 µs;
256 colunas a 1800 RPM deixam 22,96 µs antes do overhead. A documentação do
driver dá ordem de **20 µs adicionais por transação de interrupção**: restariam
~2,96 µs, sem garantia de pior caso. A 2000 RPM/256 colunas a janela é 117,19 µs
e esse orçamento não fecha. A 2000 RPM/180 colunas em 20 MHz restariam só
~3,67 µs após esse overhead. Nenhum desses modos é considerado validado.
[Driver SPI ESP32-C3](https://docs.espressif.com/projects/esp-idf/en/v5.5/esp32c3/api-reference/peripherals/spi_master.html).

Validar com analisador lógico/osciloscópio o clock real, o tempo máximo entre
quadros e o atraso do índice até a saída, sob a carga de firmware prevista.
DMA e buffer duplo são escolhas de implementação; não comprovam jitter.

## 6. Firmware — o mínimo

```
ÍNDICE     interrupção na borda do A3144, uma vez por volta
           T_volta = t[n] − t[n−1]        (mede a rotação real)
           coluna k dispara em  t[n] + k · T_volta / 180

MAPEAMENTO um quadro = 87 LEDs, na ordem física da cadeia
             LED  0 – 28  → painel 1, ângulo θ
             LED 29 – 57  → painel 2, ângulo θ + 120°
             LED 58 – 86  → painel 3, ângulo θ + 240°
           acrescentar a fase correspondente ao instante real de atualização
           de cada LED, além da calibração de zero do Hall

SPI        20 MHz solicitado p/ 180 colunas, modo 0, DMA, buffer duplo
           quadro APA102: 32 bits de início + 87 × 32 + 44 de fim
           confirmar protocolo do lote HD107S e clock efetivo; ver §5

CORRENTE   limitar soma RGB a f <= 80% e I_saida medida <= 4,25 A
           reduzir mais se a qualificação do buck real exigir
           vale sobre qualquer imagem, inclusive as que chegam pelo rádio

RÁDIO      só recepção por ESP-NOW (§9): Wi-Fi em modo estação, sem conexão,
           no canal da base; nenhuma página nem ponto de acesso no rotor
           potência de transmissão limitada a 8,5 dBm (antena da Super Mini)
           imagem nova entra no buffer de trás e só vale no pulso de índice
           interrupção das colunas acima das do rádio; tremor medido (§9.4)

BATERIA    LiFePO4 2S: 7,2 V cheia · 6,6 no platô · 5,0 vazia
           ATENÇÃO (pendência C7): confirme a ENTRADA MÍNIMA do buck real.
           Muitos módulos "mini560 5 V" pedem 7 V (ou V_out + 1,5 V). Se for
           esse o caso, o conversor passa quase toda a descarga em dropout,
           entrega V_in menos a queda e cai abaixo dos 4,5 V que garantem o
           V_IH da fita. O corte "em 5,8 V pelo dropout do buck" é PREMISSA,
           não datasheet. Mínimo aceitável: <= 5,5 V, ou trocar por buck-boost.
           ADC a cada 2 s; aviso/apagamento em 1,38 V (= 5,8 V)
           o limiar depende do buck real, não é proteção da química
           apagar a imagem não desconecta ESP/buck/bateria: definir proteção
           contra descarga profunda e estado de falha antes da integração
           divisor 150k/47k: 8,4 V lê 2,00 V. NÃO use 100k/56k — daria
           3,02 V, e o ADC do ESP32-C3 a 12 dB só é linear até ~2,5 V,
           então bateria cheia cairia na região não linear.
```

A atualização óptica precisa ser verificada, pois a HD107S pode atualizar cada
LED ao receber seu quadro de 32 bits. A 20 MHz, LEDs homólogos de painéis
consecutivos chegam separados por 29 × 32 / 20 MHz = **46,4 µs**, ou **0,501°**
a 1800 RPM; entre painéis 1 e 3 são **1,002°**, meia coluna de 180. O mapeamento
deve compensar esse atraso se confirmado no lote real; não atribuir toda imagem
tripla à montagem. [Descrição de atualização HD107S, Rose Lighting](https://www.rose-lighting.com/wp-content/uploads/sites/53/2020/05/HD107S-5050-Specificaion-V1.0.1.pdf).

## 7. Montagem na baia

Layout no CAD (`spider.bay_layout`; render `exports/preview/montagem_baia.png`).
Coordenadas do rotor: braço 1 em +x, Z = 0 no topo do cubo.

| Item | Envelope | Onde | Massa (catálogo) |
|---|---:|---|---:|
| Bateria LiFePO4 2S | 58 × 30 × 17 | berço central, deitada em y, sobre trilhos em Z = 9; a arruela e a porca fina terminam em Z = 5 | 50 g (medida) |
| Placa de interface: 74AHCT125, pull-up do hall, pull-downs de CLK e DATA, divisor, polyfuse, chave slide, JST-XH | 15 × 20 × 8 | +x, x 19,5…34,5 · y −5…15, em pilares de 6 mm, sob a janela da tampa; os terminais do hall sobem debaixo dela | 5,5 g |
| ESP32-C3 Super Mini | 18 × 22,5 × 5 | −x, x −36…−18 · y ±11, em pilares de 6 mm; USB-C para −y | 3,0 g |
| Buck 5 V mini560 | 22 × 17 × 6 | em pé numa ranhura na parede da baia a 140°, indutor para dentro | 2,0 g |
| C bulk 1000 µF | Ø10 × 20 | em pé numa cerca em (22,5, −22), lado +x | 2,5 g |
| Fios internos | — | — | 2,0 g |
| A3144 **nu** | TO-92 | bolso na face inferior do cubo, r = 29 mm, azimute 20° — **não use a placa HW-477** | 0,2 g |

A baia tem **Ø78 × 29 mm** (cubo Ø92), com 24 mm úteis acima da porca. Tudo
elevado em pilares deixa o piso livre para os três feixes dos painéis, que saem
pelas janelas da parede em Z 0,8–5,8.

**A baia é intrinsecamente assimétrica**, e o esboço mostra quanto: com essas
massas de catálogo, somados os centróides que o gerador mede na aranha e na
tampa e o sensor hall, o desbalanceamento nominal é de **63,2 g·mm a 23°**, sete
vezes o admissível. A direção da correção não cai dentro de nenhum alívio, então
ela é repartida: **2,19 g de tungstênio no alívio de 180° e 0,86 g no de 300°**,
na face inferior do cubo (r ≈ 33). O gerador refaz essa conta a cada mudança de
posição ou massa: **pesar cada peça real e atualizar `mass_g`** antes de fixar.
Tudo que entrar aqui precisa ficar onde o CAD diz: **1 mm de excentricidade em
50 g já são 50 g·mm**, seis vezes o admissível.

---

## 8. A parte fixa

```
Fonte de bancada ──── ESC LittleBee Spring 20A ──── motor A2212 920KV
   6–7 V, ≥ 5 A        BLHeli_S, sinal servo            3 fases
        │                      ▲
        │                      │ PWM 1–2 ms, 50 Hz · D25, pull-down 10 kΩ
        └──── GND ─────── ESP32 da base: rampa (§8.2) e página (§9)
                               │
                  botões de partida (D32) e de parada (D33)
```

### 8.1 Por que um microcontrolador, e qual

Um gerador de bancada produz o pulso de 1–2 ms sem dificuldade, mas **a rampa é
a função que importa** — variar a largura de pulso de 1000 para o alvo ao longo
de pelo menos 12 segundos — e isso ele não faz bem.

E o ESC **não tem tempo de rampa**: o manual do BLHeli_S expõe *startup power*,
não duração. A rampa é responsabilidade deste gerador, inteira.

**A placa é a ESP32 DevKit de 30 pinos em mãos**, no lugar do Arduino previsto
antes. O módulo é um "ESP-32" genérico, com marcação XX5R69, não o
ESP32-WROOM-32 da Espressif. Ela gera o pulso pelo PWM por hardware (LEDC), que
o Wi-Fi não perturba, e também hospeda a página do §9. Programando pelo núcleo
Arduino-ESP32, o Wi-Fi roda no núcleo 0 e o `loop()` da rampa no núcleo 1.
Confirmar no log de gravação que o chip tem dois núcleos
(`Features: WiFi, BT, Dual Core`). Com um núcleo só a placa ainda serve, porque
o pulso é por hardware.

A placa fica com o operador, fora do plano do rotor, com o cabo de sinal até o
ESC. Pinos, com os nomes impressos na placa:

| Sinal | Pino | Ligação |
|---|---|---|
| Sinal do ESC | D25 | pull-down de 10 kΩ ao GND: no reset e no boot o pino flutua |
| Botão de partida | D32 | botão ao GND, pull-up interno |
| Botão de parada | D33 | botão ao GND, pull-up interno |
| GND | GND | comum com o ESC e a fonte de bancada (§8.3) |
| Alimentação | micro-USB | carregador ou notebook; uma fonte só (§8.3) |

Evitar D2, D5, D12 e D15 (strapping; o D2 costuma acender o LED azul da placa),
TX0 e RX0 (USB), D14 (solta PWM no boot) e D34, D35, VP e VN (só entrada).

### 8.2 O que o firmware do gerador precisa fazer

```
ARMAÇÃO   ao ligar, manter 1000 µs por ~2 s antes de qualquer coisa.
          O BLHeli_S só arma vendo mínimo estável; sinal ausente ou
          alto na energização = ESC não arma, por segurança.

RAMPA     começa só pelo botão de partida (D32).
          de 1000 µs até o alvo em >= 12 s, linear no comando.
          Confirmar a rampa de RPM: pulso linear não garante aceleração linear.
          Com J=0,00155 kg.m² e T_arrasto=51,4 mN.m, 12 s dão 7,30 A
          de fase e ~4,02 A na fonte de 7 V (eta_ESC=95%).
          8 s dariam 8,47 A/~4,98 A e reprovam o teto de 8 A/4,6 A.

PARADA    normal: botão de parada (D33) -> 1000 µs; confirmar resposta do ESC
          na bancada.
          emergência: corte físico da fonte acessível ao operador.
          Nenhuma ação garante parada imediata; contenção fechada até rotor
          visivelmente imóvel e pelo menos 90 s após corte (plano de ensaios).

TETO      a única função que escreve no PWM limita o pulso ao valor que dá
          1800 RPM, medido com o tacômetro na tensão de fonte em uso: sem
          governor, o mesmo pulso gira mais rápido com mais tensão. A 1800 RPM
          o motor está a 26 % da rotação a vazio (§8.3): um pulso errado leva
          o rotor muito acima disso.

WATCHDOG  ligado. Se o firmware travar, o PWM por hardware continua no último
          pulso e o botão de parada deixa de responder; o watchdog transforma
          a trava em reset, o pulso some e o ESC desliga o motor. Confirmar na
          bancada, junto com a PARADA.

REINÍCIO  depois de qualquer reset, 1000 µs e espera o operador. A rampa nunca
          recomeça sozinha.

PÁGINA    nenhum comando de motor na página do §9, nem escondido. O motor só
          se comanda pelos botões.

PATAMARES para o Bloqueador A: 600, 1000, 1400 e 1800 RPM, 2 min cada.
```

### 8.3 Três coisas que costumam queimar tempo

**GND comum.** ESP32 da base, ESC e fonte de bancada precisam compartilhar o
terra. Sem isso o ESC lê ruído em vez de sinal. É o erro mais comum e o mais
difícil de diagnosticar.

**Nível lógico e alimentação.** O ESC aceita 3,3 V ou 5 V no fio de sinal, e a
ESP32 entrega 3,3 V. A placa se alimenta pela micro-USB; o BEC do ESC, se
houver, **não** deve alimentá-la ao mesmo tempo — uma fonte só.

**Configuração do ESC**, antes de qualquer ensaio de rotação:

| Parâmetro | Valor | Motivo |
|---|---|---|
| Direction | conforme o sentido anti-horário visto de cima | bordo de ataque em +y |
| **Brake on stop** | **desabilitado** | frear 27,6 J contra fonte de bancada empurra o barramento |
| **Low RPM power protect** | **desabilitado** | a 1800 RPM estamos a 26 % da rotação a vazio, o regime que ela limita |
| Startup power | começar baixo e subir | é o ajuste da partida com inércia 100× a de uma hélice |

### 8.4 Opcional, mas provavelmente vale

O LittleBee Spring usa um EFM8BB21, suportado pelo **Bluejay**. A opção de
reflash exige identificar o alvo exato e implementar/verificar **DShot
bidirecional na ESP32 da base**, cujo periférico RMT gera e lê esse sinal,
inclusive a conversão de RPM elétrica pelo número
de pares de polos. Bluejay não aceita o sinal servo PWM de 1–2 ms deste plano;
reflash isolado interrompe esse controle. Não retirar o tacômetro antes de
qualificar a leitura de RPM. Ela também não substitui a referência angular
1/rev necessária ao balanceamento. [FAQ oficial Bluejay](https://github.com/bird-sanctuary/bluejay/wiki/FAQ).

Não adiciona governor. Se o Bloqueador E mostrar imagem instável, a malha se
fecharia aqui, na ESP32 da base — mas a conta de estabilidade indica que não será
preciso: a inércia do rotor mantém a variação entre voltas em 0,03 a 0,11 %,
contra 0,14 % de orçamento.

---

## 9. Imagem pelo celular: página na base, rádio até o rotor

Planejado, não implementado. O público lê um QR code, desenha ou escolhe uma
imagem no celular, e ela aparece no display. A página e todo o trabalho de rede
ficam na ESP32 da base; o ESP32-C3 do rotor só recebe e projeta. **O hardware do
rotor não muda.**

```
celular ── Wi-Fi ──► ESP32 da base: rede própria, portal cativo, página,
                     fila e aprovação
                          │ ESP-NOW, mesmo canal, só imagem
                          ▼
                     ESP32-C3 do rotor: confere e troca no pulso de índice
```

### 9.1 O que a imagem é

- A volta tem **180 colunas × 29 linhas**. No raio de 100 mm, cada pixel tem
  3,5 mm de largura e 6,9 mm de altura. A página desenha a grade com células duas
  vezes mais altas que largas, para o desenho sair como na tela.
- De frente, uma pessoa vê bem cerca de um terço da volta, uns 60 × 29 pixels.
  Para o desenho livre há duas opções, **a decidir**:
  - **Carrossel de três quadros de 60 × 29.** O desenho novo ocupa um terço da
    volta, e os dois anteriores ocupam os outros dois terços. A imagem gira
    devagar em volta do cilindro, uma volta a cada 20–30 s, então todo desenho
    passa na frente de todo mundo. Um desenho novo substitui o mais antigo; o
    rotor guarda os três, 15,7 KB.
  - **Tela única de 180 × 29.** O desenho cobre a volta inteira, como um
    panorama. No celular é uma faixa três vezes mais larga que alta, desenhada
    com o aparelho deitado, e também pode girar devagar.
- A conversão acontece no navegador do celular: fotos são reduzidas e têm o
  brilho limitado antes de sair. O limite de corrente do §5 continua no firmware
  do rotor e vale sobre qualquer imagem.
- A galeria fica gravada na flash de 4 MB do rotor, onde cabem mais de cem
  imagens de 180 × 29. Escolher uma imagem manda só o número dela.

| Conteúdo | Tamanho | Pacotes ESP-NOW |
|---|---:|---:|
| Escolha na galeria | 2 bytes | 1 |
| Quadro do carrossel, 60 × 29 RGB | 5 220 bytes | 22 |
| Tela única, 180 × 29 RGB | 15 660 bytes | 65 |

### 9.2 A ESP32 da base

- **Núcleo 0:** Wi-Fi como ponto de acesso próprio (WPA2), servidor web, DNS do
  portal cativo e ESP-NOW no mesmo canal. **Núcleo 1:** rampa e botões do §8, sem
  mudança.
- **QR code** no formato de rede Wi-Fi, `WIFI:T:WPA;S:<rede>;P:<senha>;;`. O
  celular entra na rede e o portal cativo abre a página sozinho, como em Wi-Fi de
  hotel. A página fica gravada na flash da placa e não depende de internet.
- **Fila e aprovação.** Desenhos livres entram numa fila, e o operador aprova numa
  página protegida por senha, no celular dele. Escolhas da galeria dispensam
  aprovação. Cada imagem fica no ar por um tempo mínimo, por exemplo 20 s.
- **Canal fixo**, escolhido no local entre 1, 6 e 11: o menos ocupado.
- **Nenhum comando de motor na página**, nem escondido (§8.2).

### 9.3 Protocolo

- ESP-NOW unicast da base ao rotor, em pacotes de até 250 bytes: cabeçalho de
  8 bytes (tipo, número da imagem, índice e total de pacotes, largura em colunas)
  e até 242 bytes de pixels.
- O último pacote leva o CRC-32 da imagem. O rotor responde "recebida" ou a lista
  do que faltou, e a base reenvia só isso.
- O rotor monta a imagem no buffer de trás e só a troca no pulso de índice
  seguinte, nunca no meio de uma volta.
- Opcional: a cada poucos segundos, o rotor devolve a tensão da bateria (§6) e a
  rotação medida pelo índice, para a página do operador mostrar a hora de trocar a
  bateria. Isso não substitui a instrumentação do plano 04.

### 9.4 O rotor e o que precisa de ensaio

**Tremor.** O ESP32-C3 tem um núcleo só, e cada coluna sai de uma interrupção.
Uma interrupção do rádio pode atrasar a coluna: 10 µs já são 0,1° a 1800 RPM, e
o orçamento é 1/4 de coluna, **46 µs**, o mesmo que o plano 04 usa para a
estabilidade da rotação. Por isso o rotor só escuta, a interrupção das colunas
fica acima das do rádio e a troca de imagem espera o índice (§6, RÁDIO). Se o
ensaio mostrar tremor acima do orçamento, o recurso são **janelas de rádio**: o
rotor liga o rádio a cada poucos segundos, avisa que está pronto, recebe e
desliga. A base guarda a imagem até lá.

**Rádio girando.** O giro em si não atrapalha: a antena anda a ~5 m/s em
r ≈ 27 mm, e o desvio Doppler é de ~40 Hz. O que atrapalha é a bateria e o motor
perto da antena, e a antena mal projetada dos primeiros lotes da Super Mini.
Limitar a potência a 8,5 dBm costuma resolver, e o rotor quase só transmite
confirmações.

**Contenção.** Com o enlace, ela precisa deixar passar 2,4 GHz: policarbonato,
não tela de aço.

O ensaio está no plano 04 ("Enlace de imagem"), e a pendência, na 06 C11.

### 9.5 Para exibir em público

- **Contenção fechada permanente**, com o público do lado de fora. O invólucro
  está fora do escopo hoje (06); uma exposição pública o traz de volta.
- **Autonomia** de 34 min com a imagem a 30% do brilho total e de 66 min a 15%
  (§5). Imagens com fundo preto rendem mais.
- **Troca de bateria.** O pack de 50 g precisa voltar sempre à mesma posição: 1 mm
  de desvio já são 50 g·mm, seis vezes o admissível (§7).
- **2,4 GHz lotado** numa feira: escolher o canal no local e repetir lá o ensaio
  de alcance.

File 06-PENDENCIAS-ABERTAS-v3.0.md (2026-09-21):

# Pendências abertas — Hologram Orbiter v3.0

O que **falta**, depois da regeneração do CAD de 03/09/2026 (rev. 3.0.3) e da
incorporação da **revisão independente** do mesmo dia. Os códigos (B'1, C2,
D1…) são os da revisão de 02/09 e continuam valendo; o que fechou está resumido
no fim.

A revisão independente de 03/09 circulou como documento 08 solto; ela foi
**incorporada aqui** e o documento apagado. As notas "REVISAO 03/09 item N" em
`parameters.json`, no gerador e nos documentos apontam para a tabela de
disposição no fim deste arquivo.

**Última atualização:** 21/09/2026 — acrescentadas a C10 e a C11. Antes: 08/09/2026, rev. local 3.0.4. As disposições de 03/09 no fim são históricas; os cálculos corrigidos em 08/09 prevalecem.

---

## Abertas

### B'1 · Eixo do motor — medir antes de comprar a porca

O desenho cotado do A2212 mostra um **colar Ø8 × 5** sob a rosca M6 × 7, dentro
de uma saliência total de 14 (a soma dá 12: os 2 mm restantes devem ser um
ressalto sob o colar). O colar sobe acima do fundo de qualquer rebaixo do cubo
de 6 mm, e a arruela M6 Ø20 da spec assentaria nele — a porca não apertaria o
cubo. A fixação foi refeita sem rebaixo, com **arruela Ø20 × Ø8,5 × 2 em
alumínio** (disco na referência de corte da chapa) e **porca M6 fina DIN 439B
com Loctite 243**, e vale nas duas leituras do desenho: sobram 3 mm de rosca
com a ponta em 14, 1 mm com 12.

**Medir no motor, a partir da face em que o cubo assenta:** altura do topo do
colar e da ponta do eixo. Campos `unverified_interfaces.shaft.*`.

### C2 · Polaridade do ímã — decidida, confirmar na bancada antes de colar

**Decisão de Pedro, 03/09: a face positiva do ímã aponta para o sensor
(repulsão).** Registrada em `unverified_interfaces.magnet.polarity`.

**Um alerta antes de colar.** O A3144 é unipolar e comuta com o **polo sul**
apresentado à **face marcada** (serigrafada) do TO-92 — é assim que a família
A314x é especificada. "Face positiva" costuma designar o **norte** do ímã. Se as
duas convenções valerem como escritas, o ímã está invertido e **não haverá pulso
de índice** — exatamente a falha que esta pendência existe para evitar, e cujo
sintoma parece problema de firmware.

Como "positiva" e "repulsão" dependem de qual ímã de referência foi usado no
teste, a nomenclatura não resolve sozinha. **O ensaio de bancada resolve, e leva
um minuto:**

1. Alimentar o A3144 nu com **VCC=5 V**, GND comum local e **pull-up de 10 kΩ para 3,3 V**. A alimentação mínima garantida do A3144 original é 4,5 V.
2. Aproximar a face escolhida do ímã da **face marcada** do TO-92, a ~3 mm
   (o entreferro efetivo do projeto — ver C8).
3. A saída tem de ir a **nível baixo**. Se não for, é a outra face.

Só depois disso a cola entra. Fazer junto com C3 (campo do motor) e C8
(entreferro), que exigem a mesma montagem.

### C3 · Campo do motor sobre o sensor

O sensor gira a ~15 mm do rotor de ímãs do motor. Esse campo é estático em
relação ao sensor e pode mantê-lo permanentemente ligado ou desligado.
**Verificar com o motor montado, antes de colar.**

### D1 · Layout e massa real da eletrônica

O buck permanece a 140° com envelope/guia recuados 1,2 mm radialmente (wall_gap=1,5 mm). A colisão com a raiz é verificada por interseção contra a malha final. Medir o módulo real, principalmente indutor, soldas, fios e retenção.

Os cinco componentes da baia continuam com 15 g estimados. Consultar `reports/geometry_report.json` para o vetor e os contrapesos desta execução. Pesar componentes e peças impressas, pois infill e distribuição dos chicotes mudam centróides. O Hall entra tanto no vetor quanto no subtotal de massa.

### R01 · Resistência e fluência dos painéis — bloqueia o lote definitivo

A seção foi corrigida para Iyy=589,8846 mm⁴. O envelope de viga com 44,5 g dá 3,83–7,74 mm; com o teto de 45 g, chega a 7,83 mm / ~29,1 MPa. A aproximação não certifica engaste, transferência de carga, ABS FDM ou fluência. Fechar essas verificações e decidir eventuais mudanças de perfil antes de fabricar o lote definitivo. O cálculo distribuído parcial em `FISICA.json` não é um limite de aceite.

### R04/R05 · Instrumentação e método de ensaio — ainda não executados

Seguir o plano 04 corrigido: termopar somente em parte fixa com ponto validado, medição apropriada da campânula/bateria girantes e referência fixa 1/rev sincronizada. Balanceamento em dois planos exige observações independentes e massas de teste em cada plano. Equipamentos e métodos ainda precisam de qualificação; não registrar aprovação por ausência de medição.

### C7 · Buck mini560 — tensão mínima de entrada · **comprar só depois**

A maioria dos módulos "mini560 5 V" anuncia entrada de **7 a 20 V** (ou
V_out + 1,5 V). O pack é LiFe 2S: 7,2 V cheio, **6,6 no platô**, corte em 5,8.
Se o mínimo real for 7 V, o conversor passa quase toda a descarga em *dropout*,
entrega V_in menos a queda e cai abaixo dos **4,5 V que garantem o V_IH da
fita** — e o "corte em 5,8 V pelo dropout do buck" que o esquema 05 usa é
premissa, não datasheet.

**Fechar assim:** obter o datasheet do módulo exato que for comprado. Aceitável
se V_in mínima ≤ 5,5 V. Caso contrário, trocar por um buck síncrono de entrada
baixa ou um **buck-boost** — o que muda a linha de potência inteira do rotor.
É a pendência de maior alcance ainda aberta, e é anterior à compra.

### C8 · Entreferro do sensor hall — medir antes de colar

Cotas do CAD: bolso do sensor 1,7 mm para um TO-92 de 1,5; bolso do ímã 2,2 para
um ímã de 2,0; entreferro nominal 2,5. **Face a face dá 2,9 mm**, e a pastilha
do A3144 fica ~0,5 mm dentro do encapsulamento: **~3,4 mm efetivos**.

Campo axial de um disco N35 Ø4 × 2 (Br 1,2 T) no eixo:

| distância | B |
|---:|---:|
| 2,5 mm | 80 mT |
| **3,4 mm** | **45 mT** |
| 4,0 mm | 33 mT |
| 4,5 mm | 25 mT |

O A3144 original tem **B_OP máximo de 35 mT a 25 °C e 45 mT na faixa térmica**. Portanto, 45 mT de campo nominal não dão margem térmica garantida; **+1 mm
de erro no entreferro e o sensor pode não comutar** nas peças de pior caso. Pior:
o entreferro é a única cota da máquina que depende da altura real do conjunto
motor (`motor_stack.plate_top_to_bell_face`, medida mas com
`seat_assumption_verified: false`) — ±2 mm ali levam o entreferro de 0,5 a
4,5 mm.

**Fechar assim:** medir o entreferro com o motor e o rotor montados, **antes de
colar o ímã**. Se passar de 3,0 mm, usar calços sob o poste, ou um ímã **Ø5 × 3
N52** (~2× o campo). Ver também C2 (polaridade) e C3 (campo do motor).

### C9 · ESC a 6 V · saída dos fios de fase

**O ESC não é alimentado pela bateria** (ratificado por Pedro, 03/09, e já era o
que o esquema 05 §8 descrevia): ele fica na **parte fixa**, alimentado pela
**fonte de bancada em 6–7 V, ≥ 5 A**. A bateria LiFe do rotor alimenta só a
fita, o ESP32-C3 e o sensor. As duas linhas de energia não se encontram.

Isso encerra a metade da pendência que dependia da origem da alimentação, e o
**LVC também já estava encerrado**: o glossário §2–3 registra, do manual Rev16.x,
que BLHeli_S **não tem corte por baixa tensão**. Sobra um resíduo estreito:

- **Margem do ESC em 6 V.** O LittleBee Spring é especificado para **2–4S**, ou
  seja 7,4 V nominais no piso da faixa, e o projeto o opera deliberadamente em
  **6–7 V** para manter o duty alto (spec §10). O que ainda não foi verificado
  não é o LVC nem a fonte, e sim se o **regulador interno** (que alimenta o
  EFM8BB21) e o **gate driver** têm margem em 6,0 V. Gate drive fraco não
  desliga o ESC: aumenta o RdsOn e aparece como calor no ESC e comutação suja.
  **Fechar assim:** operar o primeiro ensaio em **7,0 V**, não em 6,0, e só
  descer se o ESC ficar frio e a comutação limpa. Se houver instabilidade,
  suba a tensão antes de suspeitar do sinal.
- **Fios de fase.** O motor assenta plano na chapa R01 e os fios saem pela
  lateral do estator. Para descerem pelo alívio central Ø12 e pela torre eles
  precisam de um rasgo na chapa ou de um caminho pela borda —
  `motor_plate.center_clearance_verified` já é `false`. Confirmar com o motor em
  mãos e anotar no DXF antes de cortar a chapa. Lembrar que o arco do suporte do
  ímã ocupa o lado +x: os fios saem por −x.

### C10 · Dados das fitas: cadeia ou SPI quad · **decidir antes dos chicotes**

O esquema 05 liga as três fitas em cadeia numa única saída SPI. A alternativa
é o modo quad do SPI2, com um clock comum e uma linha de dados por fita.
Ela triplica a folga de tempo por coluna e elimina a defasagem de 0,5° e 1°
entre painéis. Também reduz cada chicote de seis para quatro condutores
(~1,5 g a menos no rotor), sem peça nova e sem mudar o CAD. Os riscos são o
CLK dividido em três ramos e a ordem dos bits no modo quad.

**Fechar assim:** ensaios A a C da
[proposta de 21/09](revisoes/2026-09-21-PROPOSTA-SPI-QUAD.md), com as três
fitas e fios no comprimento real. Decidir antes de montar os chicotes e o
lastro do G3 (plano 04). Até lá, vale a cadeia do 05.

### C11 · Enlace de imagem da base ao rotor · **ensaiar antes de abrir ao público**

O esquema 05 §9 planeja a página na ESP32 da base e a imagem transmitida por
ESP-NOW ao ESP32-C3 do rotor. Três incertezas:

- o tremor que o rádio causa na varredura, porque o C3 tem um núcleo só;
- o alcance com a antena da Super Mini dentro da baia fechada;
- a contenção, que precisa deixar passar 2,4 GHz.

**Fechar assim:** ensaio do enlace de imagem do plano 04, primeiro na bancada
com o índice simulado e depois girando. Se o tremor passar de 1/4 de coluna
(46 µs), usar as janelas de rádio do 05 §9.4. Antes de escrever a página,
decidir o formato do desenho livre: carrossel de três quadros de 60 × 29 ou
tela única de 180 × 29 (05 §9.1).

### D3 · Orçamento completo de massa e chicotes

O teto do rotor permanece **280 g**. O relatório publica um subtotal nominal com eletrônica de catálogo, Hall e contrapesos; ainda é necessário reconciliar as ferragens de 4 g/painel com a massa real dos chicotes de seis condutores. A estimativa antiga de fios no CG não foi uma pesagem e não garante sua inclusão na soma.

Pesar todos os componentes e o rotor completo. Só então registrar margem, ajustar contrapesos e recalcular o desbalanceamento admissível. Não reduzir margens estruturais nem aumentar o teto para acomodar componentes não medidos.
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

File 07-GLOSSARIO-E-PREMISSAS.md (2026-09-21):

# Glossário e premissas — Hologram Orbiter v3.0

Duas coisas que faltavam: o vocabulário do projeto, e o registro honesto de
**o que foi medido, o que foi derivado e o que ainda é chute**.

---

## 1. Vocabulário

### Motor

**Campânula** *(bell)* — a parte **girante** do motor: a "sineta" de alumínio que
gira por fora, com os ímãs colados na face interna. É nela que a aranha se apoia
e dela que sai o eixo. **Não confundir com o cilindro de proteção.** Neste motor
ela é vazada, com 5 raios, e não tem furos roscados.

**Base do motor** — a parte **fixa**, onde saem os três fios de fase. É ela que
parafusa na chapa de alumínio, pelo padrão de 4 × M3 em retângulo 16 × 19 mm.

**Colar do eixo** — o trecho Ø8 × 5 mm do eixo entre a campânula e a rosca M6.
É ele que centra o cubo (furo Ø8 H8), e é por ele que a arruela precisa de furo
Ø8,5: uma arruela M6 assentaria no colar e a porca não apertaria o cubo.

**kv** — rotação por volt sem carga. 920 kv em 7 V dá 6440 RPM a vazio; a
1800 RPM o motor está a aproximadamente 28 % disso. A base das tabelas de fonte é 7 V.
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

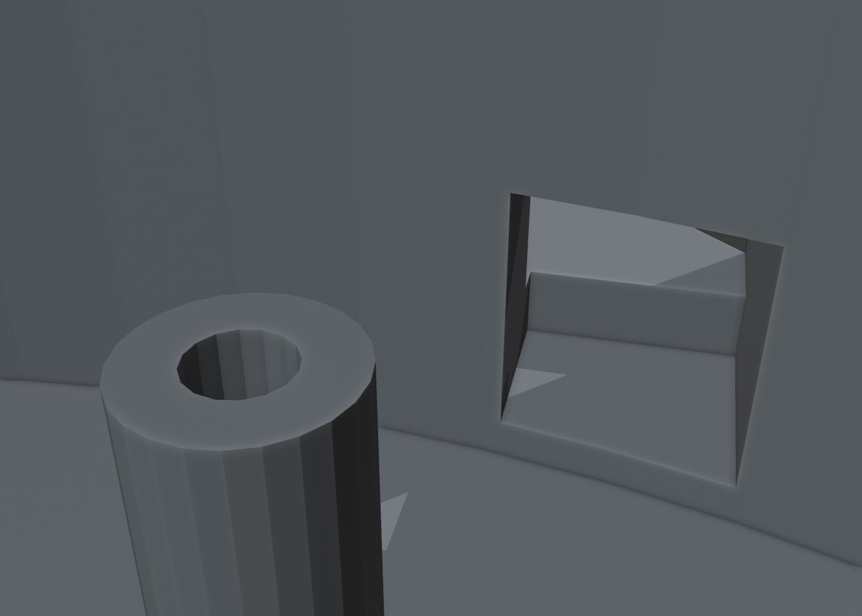
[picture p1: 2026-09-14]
proposta/apresentacao/img/aranha_entrada_fios.png

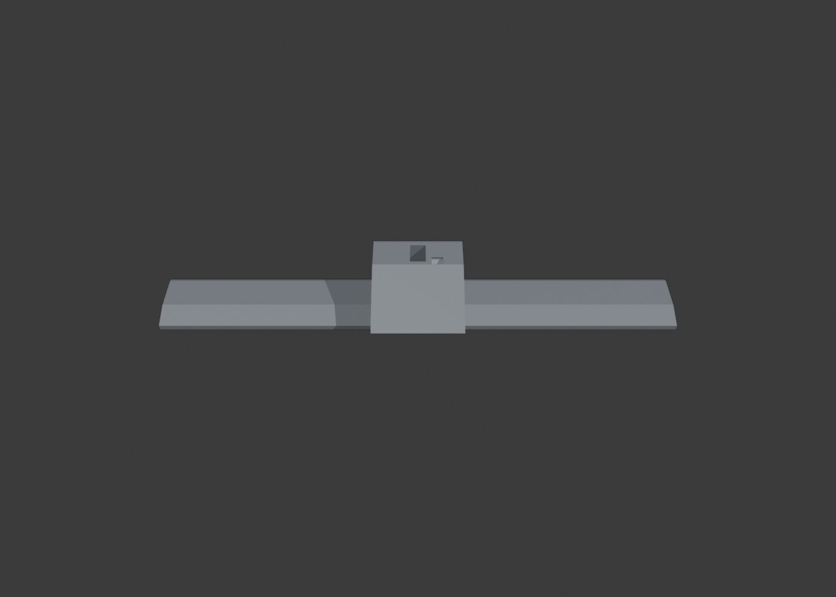
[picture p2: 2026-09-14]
proposta/apresentacao/img/painel_completo.png

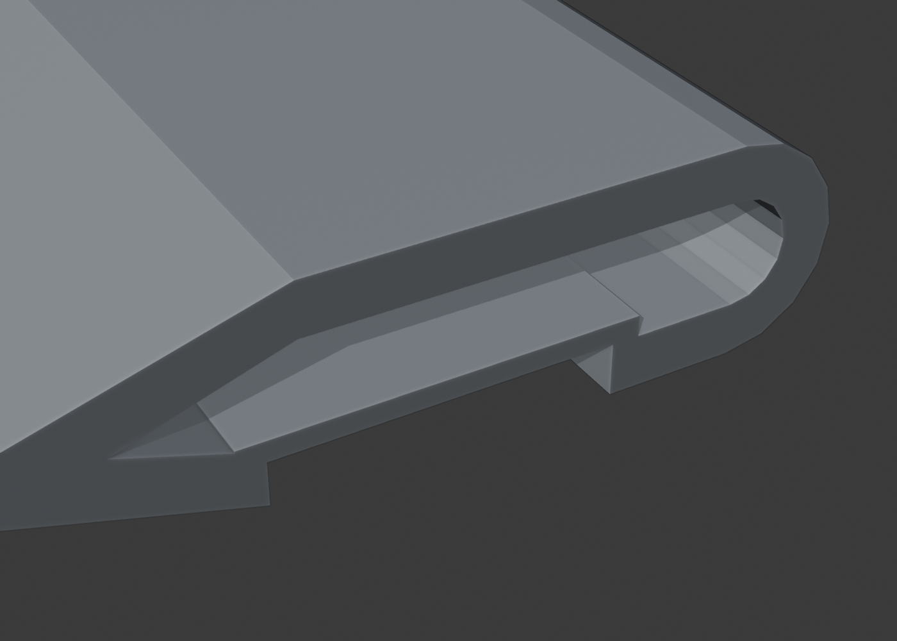
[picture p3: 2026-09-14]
proposta/apresentacao/img/cupom_canal_led_secao.png

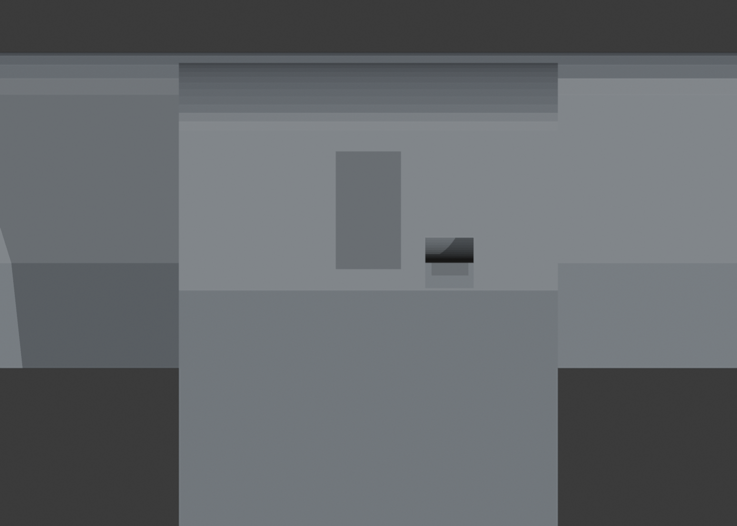
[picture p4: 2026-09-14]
proposta/apresentacao/img/painel_boss_face_contato.png

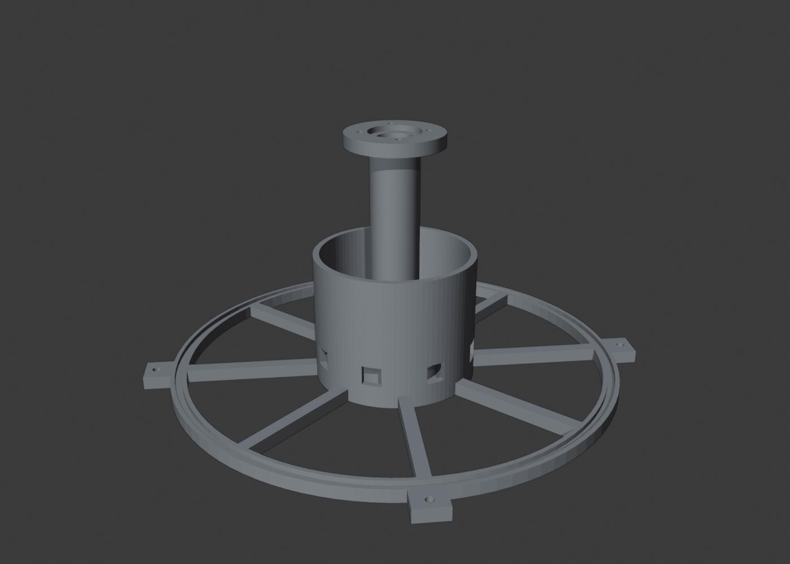
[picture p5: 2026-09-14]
proposta/apresentacao/img/base_perspectiva.png

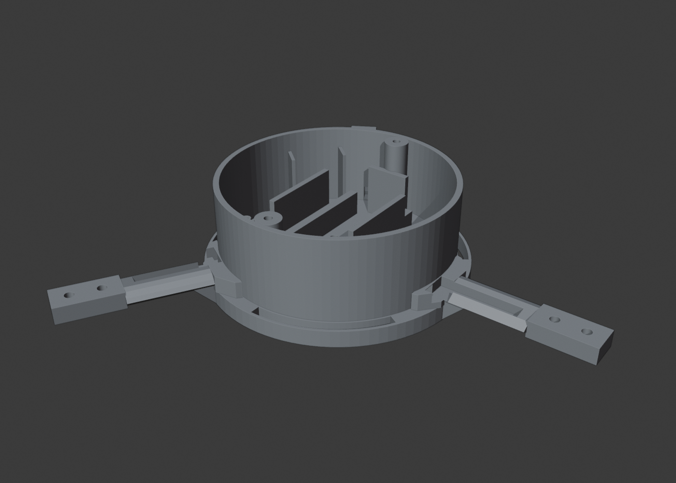
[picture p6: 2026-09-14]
proposta/apresentacao/img/aranha_perspectiva.png

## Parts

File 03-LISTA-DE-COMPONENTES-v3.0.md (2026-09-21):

# Lista de componentes — Hologram Orbiter v3.0

Revisada em 08/09/2026. Em 21/09/2026: pull-downs do 74AHCT125 e ESP32 na base no lugar do Arduino. Preços em BRL são **estimativas de ordem de grandeza**
para orçamento, não cotações.

Componentes em mãos não significam montagem validada. O buck e a instrumentação
de temperatura, fase e balanceamento continuam sem qualificação. As massas CAD
da tabela são referências anteriores à revisão 3.0.4; conferir o relatório
regenerado e pesar o conjunto com os seis condutores por painel.

Legenda: ✅ já temos · 🛒 comprar · ⚠️ decisão pendente

---

## 1. Peças impressas — ABS

Todas saem do gerador paramétrico. Ver [`01-ESPECIFICACAO-CAD-v3.0.md`](01-ESPECIFICACAO-CAD-v3.0.md).

| # | Peça | Qtd | Volume (CAD) | Massa maciça (CAD) | Limite | Tempo |
|---|---|---:|---:|---:|---|---|
| 01 | Aranha (com pilares e guias da baia) | 1 | 68,3 cm³ | 71,06 g | ≤ 75 g (alvo) | 5–6 h |
| 02 | Painel LED | 3 | 30,7 cm³ ea. | 31,9 g nu | ≤ 45 g montado | 8–10 h (lote) |
| 03 | Tampa da baia Ø82 | 1 | 9,7 cm³ | 10,1 g | ≤ 12 g (alvo) | 30 min |
| 04/05 | Base + torre integradas, 4 abas | 1 | 307 cm³ | 320 g | ≤ 330 g (alvo) | 12–18 h |
| 06 | Suporte do ímã (dois parafusos) | 1 | 1,7 cm³ | 1,7 g | — | 15 min |
| C01 | Cupom da junta 11 × 6 | 1 | 9,7 cm³ | 10,1 g | — | 15 min |
| C02 | Cupom do canal do LED (fatia real de 30 mm do painel) | 1 | 3,4 cm³ | 3,5 g | — | 10 min |

**Total: ~490 cm³ ≈ 0,5 kg em densidade maciça** (menos com infill). Comprar
**1 kg** — o refugo em ABS é real e os painéis podem precisar de segunda
tiragem por massa fora de tolerância.

**Imprimir os cupons primeiro.** Custam 25 minutos e evitam refazer um lote de
painéis de 208 mm por causa de folga na junta ou no canal.

---

## 2. Acionamento

| Item | Espec | Sit. | ~R$ |
|---|---|:--:|---:|
| Motor BLDC | **A2212 920KV**, 2–4S, 52 g, eixo M6, base 4×M3 em 16 × 19 mm | ✅ | — |
| ESC | **LittleBee Spring 20A**, BLHeli_S, 25 × 13 mm | ✅ | — |
| Fonte de bancada | ajustável; operar em **6–7 V**, ≥ 5 A | ✅ | — |
| Gerador do sinal do ESC | **ESP32 DevKit de 30 pinos em mãos** (módulo "ESP-32" genérico, marcação XX5R69), no lugar do Arduino; também hospeda a página da imagem pelo celular (§9 do esquema). Firmware de rampa **≥ 12 s**, teto do pulso, watchdog e botões ainda a implementar — ver §8 do esquema | ✅ | — |
| Botões de partida e de parada | 2 × botão momentâneo, de D32 e D33 ao GND, com pull-up interno | 🛒 | 2 |
| Pull-down do sinal do ESC | 10 kΩ, de D25 ao GND | 🛒 | 1 |
| **Arruela Ø20 × Ø8,5 × 2 mm, alumínio** | cortar da mesma chapa da R01 (a referência de corte traz o disco). O furo precisa passar pelo **colar Ø8 do eixo**, que sobe 5–7 mm acima da campânula: uma arruela M6 assentaria no colar e a porca não apertaria o cubo. Alternativa de prateleira: DIN 125 M8 em aço (Ø16; 3,4 MPa no ABS) | 🛒 | — |
| **Porca M6 fina DIN 439B** (3 mm) + Loctite 243 | **não** a cônica de 14 mm que veio com o motor, **nem** a autotravante baixa de 6 mm: com o colar até 5–7 mm e a rosca acabando em 12–14, a de 6 mm terminaria no fim do eixo. Apertar a **0,6 N·m** | 🛒 | 2 |

> **Aperte a 0,6 N·m, com arruela Ø20.** O atrito precisa transmitir 46 mN·m, o
> que exige só ~22 N. A 0,6 N·m a força é de 500 N — 23× de margem — e a tensão
> no ABS fica em 1,9 MPa. Com arruela M6 padrão e 3 N·m daria 40 MPa, a tensão de
> escoamento, e a junta relaxaria em horas.

---

## 3. Óptica e eletrônica de bordo

Tudo isto gira junto com o rotor.

| Item | Espec | Sit. | ~R$ |
|---|---|:--:|---:|
| Fita LED | **HD107S 144 LED/m**, RGB, 1 m — medida em **12,0 × 2,0 mm** | ✅ | — |
| Microcontrolador | **ESP32-C3 Super Mini** (~22 × 18 mm) | ✅ | — |
| Regulador 5 V | módulo exato **pendente de qualificação** de entrada, corrente contínua e térmica. Mini560 (envelope estimado 22 × 17 × 6 mm, ~2 g) é candidato; **não comprar antes de C7**. Exatamente 5 A não cobre branco pleno; ver limite provisório abaixo | ⚠️ | 15 |
| Bateria | **LiFePO4 2S 800 mAh 20C**, 58 × 30 × 17 mm, 50 g, 6,6 V | ✅ | — |
| Conectores | **XT30 para potência** e **JST-XH de 3 vias para balanceamento**; verificar peças e contatos reais | 🛒 | 8 |
| Chave liga/desliga | componente miniatura com capacidade DC compatível com a corrente de entrada do buck; **curso tangencial** — confirmar datasheet e nota | ⚠️ | 5 |
| Sensor de índice | **A3144 nu**, dessoldado do módulo HW-477 — **no rotor** | ✅ | — |
| Resistor de pull-up | 10 kΩ, do sinal do hall para **3,3 V** | 🛒 | 1 |
| Resistores de pull-down | 2 × 10 kΩ, das entradas CLK e DATA do 74AHCT125 ao **GND** (esquema §2.2) | 🛒 | 1 |
| Deslocador de nível | **74AHCT125** para CLK e DATA, com `/OE` definidos e **100 nF cerâmico** junto ao CI; buck em 4,5 V não garante nível lógico | 🛒 | 5 |
| Divisor da bateria | 150 kΩ / 47 kΩ + 100 nF no ADC; tolerâncias e calibração a verificar | 🛒 | a cotar |
| Proteção da alimentação | fusível/polyfuse nominal 7,5 A do esquema: selecionar modelo, corrente de manutenção a quente e coordenação com fios/chave | ⚠️ | a cotar |
| Capacitor de bulk | 1000 µF / 10 V na entrada da fita | 🛒 | 3 |
| Ímã | neodímio Ø4 × 2 mm — **na parte fixa** | 🛒 | 2 |
| Fio de potência | **AWG 24**, 2 cores, ~3 m | 🛒 | 12 |
| Fio de sinal | AWG 28, 2 cores, ~3 m | 🛒 | 8 |
| Fita de poliéster transparente | 0,05–0,1 mm, retenção mecânica da fita LED | 🛒 | 15 |
| Carregador **modo LiFe** | 3,6 V/célula — modo LiPo (4,2 V) destrói o pack | ⚠️ | 60 |

> **Empacotamento — a baia foi ampliada por causa disto.** Bateria, MCU,
> regulador, deslocador de nível, capacitor, chave e conector numa baia que era
> de Ø66 × 20 mm. Passou para **Ø78 × 29**, com 24 mm úteis acima da porca. Um
> DevKit ESP32 de 55 × 28 mm não caberia junto com a bateria; o C3 Super Mini
> (22 × 18) cabe. O esboço de layout está no CAD (`spider.bay_layout`) e é
> verificado pelo gerador: placa de interface em +x sob a janela da tampa,
> ESP32-C3 em −x, buck em pé na parede, capacitor em pé numa cerca. As massas
> são de catálogo e somam exatamente os 15 g de folga: **pesar cada peça real
> antes de fixar**.

> **Tudo o que vai na baia sofre 98 a 114 g.** A aceleração centrífuga em
> r = 27–32 mm é `ω²r` = 960 a 1140 m/s². Duas consequências práticas na compra:
>
> - a **chave** precisa ter o curso **tangencial**, não radial: uma slide com o
>   curso apontando para fora se aciona sozinha sob 100 g;
> - o **capacitor** Ø10 × 20 em pé, com 2,5 g em r = 31,5, leva **2,8 N** de
>   lado no topo. Uma cerca de 3 mm no pé não segura: cole, ou use um polímero
>   SMD deitado. Confirme também que o pack é de **células rígidas** — as pontas
>   dele estão a r = 29.

> **Duas armadilhas elétricas que não são opcionais.**
>
> **O A3144 não funciona a 3,3 V** — opera de 4,5 a 24 V. Alimente-o em **5 V** e
> use o pull-up de 10 kΩ para **3,3 V**: como a saída é coletor aberto, o sinal
> oscila de 0 a 3,3 V e a entrada do ESP32-C3, que não tolera 5 V, fica protegida.
> Pull-up para 5 V queima a porta.
>
> **A fita quer V_IH ≥ 3,5 V**. O 74AHCT125 é a solução adotada. Reduzir o buck
> para 4,5 V não assegura compatibilidade: o limiar ~3,15 V ainda excede o
> V_OH mínimo garantido de 2,64 V do ESP32-C3. Ver §2 do esquema e seu datasheet.

> **O pack comprado cabe.** LiFePO4 2S de 58 × 30 × 17 mm deitado ao longo de
> y, sobre trilhos em Z = 9 que passam por cima da arruela e da porca fina (topo
> em Z = 5); o topo do pack fica em Z = 26, dentro dos 29 da baia, e a
> meia-diagonal do berço, 32,3 mm, dentro do raio útil de 39. Paredes laterais e
> abas de topo centram o pack; **a retenção é simples porque ele fica no eixo de
> rotação**: sendo simétrico em torno do centro, a resultante centrífuga sobre
> ele é praticamente nula. Uma espuma sob a tampa segura contra vibração.
>
> **O que decide, não o rótulo de aplicação:** taxa ≥ 15C (o pack tem 20C) e
> conector de balanceamento **JST-XH de 3 vias** além do de potência. Sem o
> balanceador não há carga célula a célula, e num pack que gira lacrado isso
> não é aceitável. Carregar sempre em **modo LiFe**.

> **A imagem pelo celular não pede peça nova no rotor.** O ESP32-C3 já tem
> rádio; a página e a fila ficam na ESP32 da base (esquema 05 §9). No rotor, só
> o firmware muda.

**Base de energia:** a hipótese de 60 mA por LED dá **5,22 A / 26,1 W** em
branco pleno. Com ESP de 0,3 W e buck a 87,5%, seriam 4,57 A na bateria e
10,5 min teóricos. O cenário de conteúdo equivalente a 15% dá 0,730 A e
65,8 min teóricos; a autonomia útil depende de medição, não há promessa de
50 min. O pack guarda 6,6 × 0,8 = 5,28 Wh nominais.

**Limite provisório para planejar a integração:** soma RGB equivalente a no
máximo **80% do branco e corrente total medida na saída ≤ 4,25 A**, ou menos
se o buck real exigir. O módulo deve manter regulação de 7,2 até 5,8 V sob a
carga autorizada e passar em térmica. Esse teto não qualifica um mini560
genérico; firmware de limitação e ensaio ainda precisam existir. Branco pleno
requer capacidade contínua superior a 5,28 A. Ver esquema §5 e pendência C7.

---

## 4. Estrutura e fixação

| Item | Espec | Qtd | Sit. | ~R$ |
|---|---|---:|:--:|---:|
| Chapa de alumínio | 2 mm, 60 × 60 mm, cortada e furada | 1 | 🛒 | 10 |
| Parafuso **M3 × 40** + porca **plana** M3 | fixação painel → longarina | 6 + 6 | 🛒 | 10 |
| Trava química média (Loctite 243) | substitui o nyloc nas juntas do painel | 1 | 🛒 | 25 |
| Parafuso **M3 × 6** | motor → chapa (padrão 16 × 19 mm) | 4 | 🛒 | 3 |
| Parafuso M4 × 16 (2) e **M4 × 20** (2, sob a aba de 2,5 mm do suporte do ímã) + porca nylon | chapa → flange da torre | 4 + 4 | 🛒 | 5 |
| Parafuso M3 × 10 | tampa da baia | 2 | 🛒 | 2 |
| Massa de balanceamento | fita adesiva de chumbo ou tungstênio | — | 🛒 | 20 |
| Grampos tipo C | fixação da base à bancada nos ensaios | 2 | 🛒 | 20 |
| Abraçadeiras e fita kapton | fios no rotor, termopar | — | 🛒 | 15 |

> **Correção de 02/09 — o nyloc não cabe onde eu tinha mandado usar.** O bolso
> hexagonal do painel tem **2,8 mm** e uma porca nyloc M3 tem **4,0 mm**; só entra
> porca plana (2,4 mm). Nas juntas do painel, use **porca plana + trava química**.
> Nyloc segue valendo onde há espaço: chapa → flange da torre.
>
> **E o comprimento estava errado.** A torre do boss tem 36 mm e a porca fica no
> fundo dela: o parafuso precisa de **M3 × 40**, não × 20.
>
> **Motor → chapa: M3 × 6, não × 8.** Através de 2 mm de chapa, um M3 × 8 penetra
> 6 mm na base do A2212, que aceita ~4–5 mm antes de tocar o enrolamento.

---

## 5. Instrumentação para os ensaios

| Item | Espec | Por quê | Sit. | ~R$ |
|---|---|---|:--:|---:|
| **Balança de precisão** | **resolução 0,01 g** | Δm entre painéis ≤ 0,084 g | 🛒 | 60–100 |
| Termopar tipo K + leitor | sonda de 1,5 mm, **só em pontos fixos** | chapa/base e referência estática; não ligar cabo à campânula girante | 🛒 | 40 |
| Medição da temperatura do motor em giro | sistema sem contato qualificado ou sensor embarcado retido | método, emissividade/spot ou telemetria ainda pendentes — bloqueador B | ⚠️ | a cotar |
| Medição da bateria em giro | sensor calibrado embarcado com telemetria ou registro local | temperatura máxima durante G4, com massa/retensão a incorporar | ⚠️ | a cotar |
| Acelerometria | duas respostas independentes e aquisição sincronizada; MPU6050 é candidato | matriz de influência em dois planos, não apenas um pico na base | ⚠️ | a cotar |
| Referência angular fixa 1/rev | sensor óptico ou equivalente, marca no rotor e mesma base de tempo da vibração | fase em G3, quando não há Hall embarcado | ⚠️ | a cotar |
| Paquímetro digital | 0,01 mm | verificação dimensional | ⚠️ | 30–50 |
| Tacômetro | necessário até qualificar leitura alternativa de RPM; Bluejay exige novo gerador DShot bidirecional e não fornece a referência fixa de fase | ⚠️ | 0–40 |
| Analisador lógico / osciloscópio | resolução adequada a SPI de 20–26,67 MHz | verificar clock efetivo, transações, atraso óptico/índice e o tremor com rádio (esquema §9) | ⚠️ | a cotar |
| Câmera | celular a 240 fps serve | validação visual de jitter | ✅ | — |

> **A resolução da balança é requisito, não conforto.** As versões anteriores
> pediam 0,1 g. Com Δm admissível de 0,084 g entre painéis, uma balança de 0,1 g
> **não consegue verificar o critério** — ela mede exatamente o tamanho do erro
> que precisa detectar. Precisa ser 0,01 g.

---

## 6. Consumíveis

| Item | Qtd | ~R$ |
|---|---|---:|
| Filamento ABS | 1 kg | 90–130 |
| Isopropanol, cola de mesa, lixa | — | 30 |
| Termorretrátil e solda | — | 20 |

---

## 7. Resumo de compra

| Bloco | ~R$ |
|---|---:|
| Acionamento (porca fina; a arruela sai da chapa) | 2 |
| Eletrônica de bordo | 45–65 |
| Estrutura e fixação | 83 |
| Instrumentação | 75–155 |
| Consumíveis | 140–180 |
| **Subtotal do orçamento anterior** | **345–485**, sem instrumentação e itens novos a cotar |

Carregador **em modo LiFe** (R$ 60) e paquímetro (R$ 50) entram se ainda não
houver no laboratório. A instrumentação adicional acima e as proteções impedem
fechar um total atualizado. Bluejay só dispensa o tacômetro após implementar
DShot bidirecional no gerador e validar RPM; o sinal servo existente não funciona
com esse firmware. Nenhuma compra foi realizada por esta revisão.

### Prioridade de compra

1. **Antes de comprar** — qualificar buck, chave, proteções e instrumentação;
   conferir os itens já em mãos e os seis fios isolados por painel.
2. **Antes da Fase 3** — balança de 0,01 g, medição térmica qualificada,
   duas respostas de vibração independentes e referência fixa 1/rev.
3. **Depois de medir** — isolador de vibração, se o ensaio de vibração pedir.

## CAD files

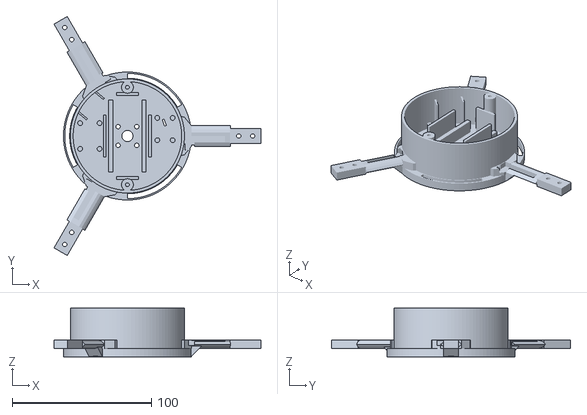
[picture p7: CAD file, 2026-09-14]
Hologram_Orbiter_v3_0/exports/stl/01_aranha_ABS.stl
148.8 x 171.8 x 35.0

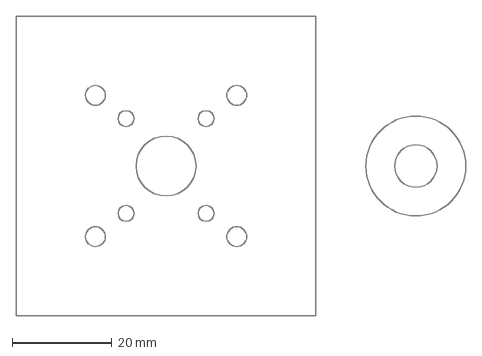
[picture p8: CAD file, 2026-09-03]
Hologram_Orbiter_v3_0/fabricacao/R01_suporte_motor_60x60_aluminio_2mm.dxf
90.0 x 60.0 mm

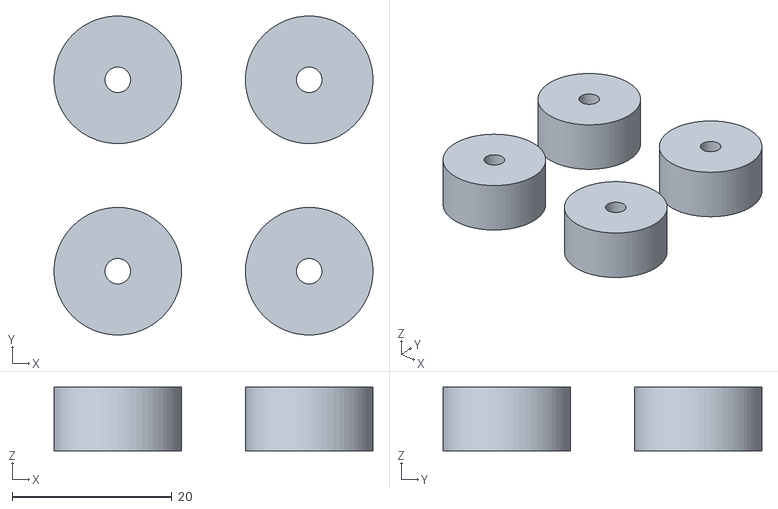
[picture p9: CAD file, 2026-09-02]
legado/Hologram_Orbiter_v2_1/exports/stl/07_coxim_TPU95A_4x_mesma_mesa.stl
40.0 x 40.0 x 8.00

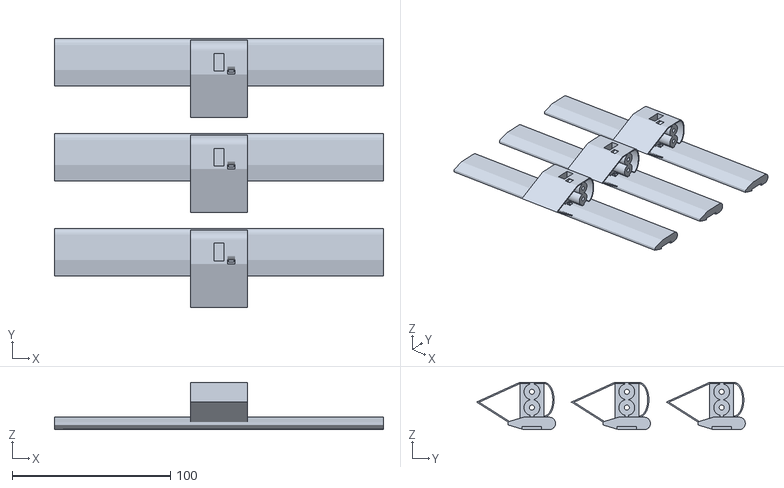
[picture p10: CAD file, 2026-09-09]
Hologram_Orbiter_v3_0/exports/stl/02_painel_LED_ABS_3x_mesma_mesa.stl
208.0 x 170.0 x 30.0

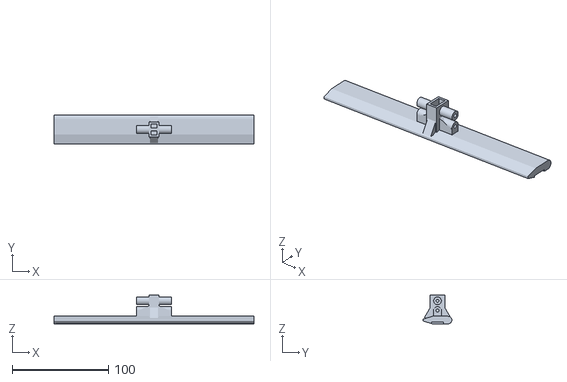
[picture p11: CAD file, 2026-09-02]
legado/Hologram_Orbiter_v2_1/exports/stl/02_painel_LED_ABS_1x.stl
208.0 x 30.0 x 30.0

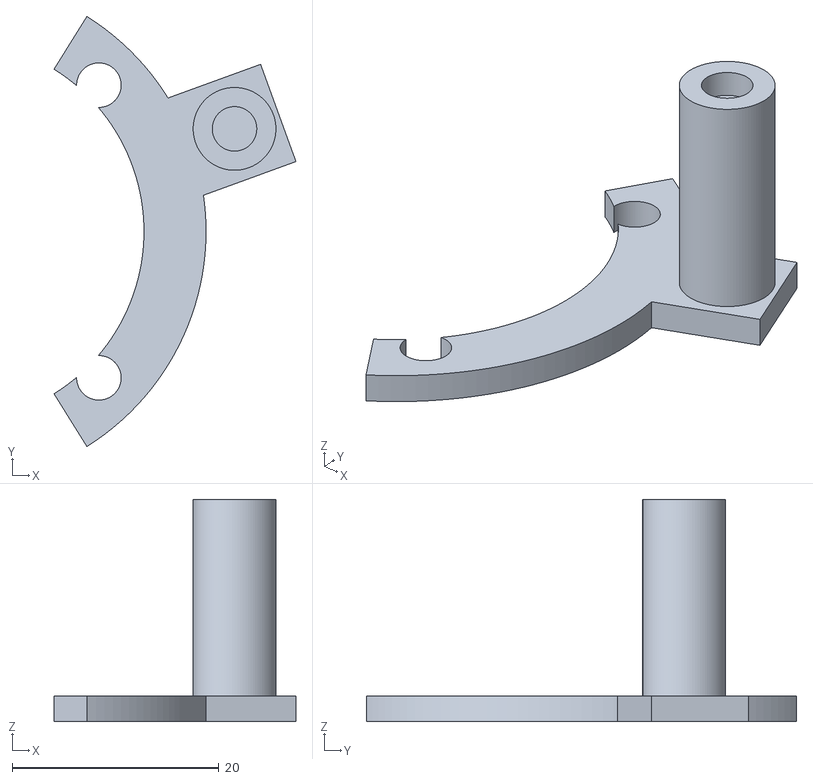
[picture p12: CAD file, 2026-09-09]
Hologram_Orbiter_v3_0/exports/stl/06_suporte_ima_ABS.stl
23.4 x 41.6 x 21.5

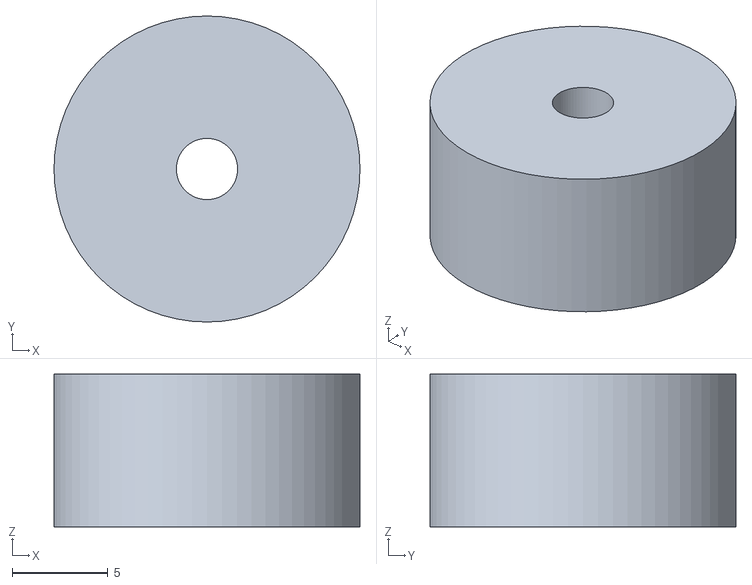
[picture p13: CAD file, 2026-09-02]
legado/Hologram_Orbiter_v2_1/exports/stl/07_coxim_TPU95A_1x.stl
16.0 x 16.0 x 8.00

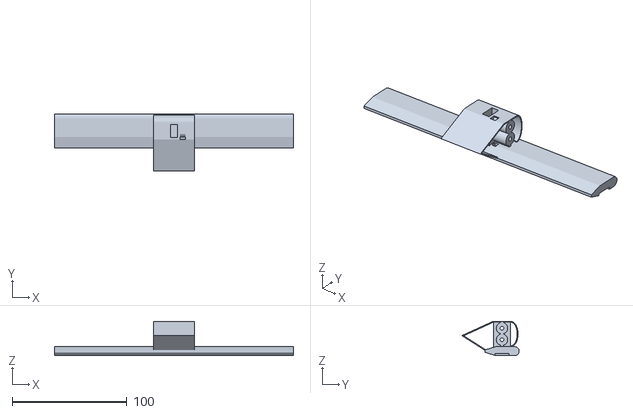
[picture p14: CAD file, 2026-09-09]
Hologram_Orbiter_v3_0/exports/stl/02_painel_LED_ABS_1x.stl
208.0 x 50.0 x 30.0

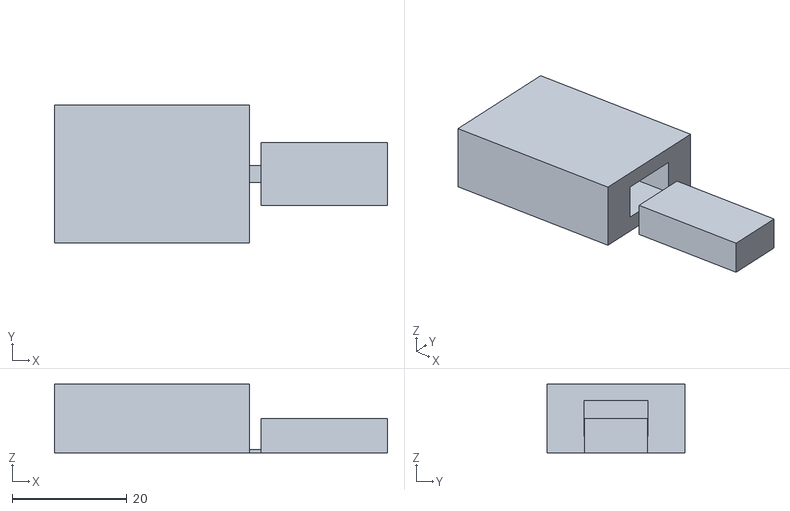
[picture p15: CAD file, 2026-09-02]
legado/Hologram_Orbiter_v2_1/exports/stl/C01_cupom_junta_11x6.stl
58.0 x 24.0 x 12.0

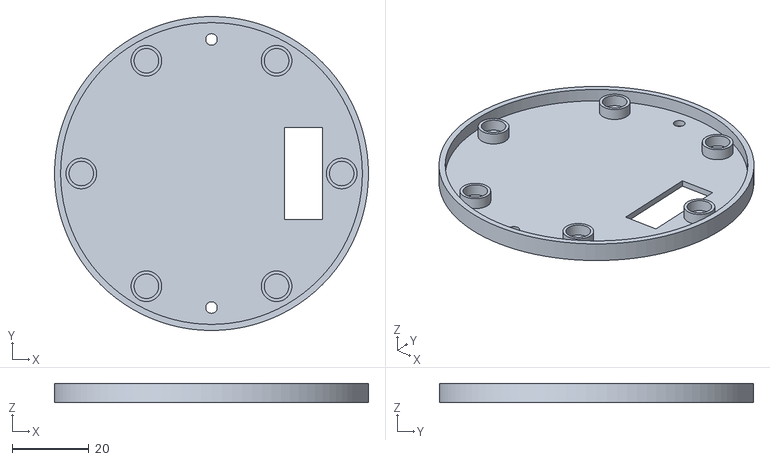
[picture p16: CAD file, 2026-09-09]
Hologram_Orbiter_v3_0/exports/stl/03_tampa_baia_ABS.stl
82.0 x 82.0 x 5.00

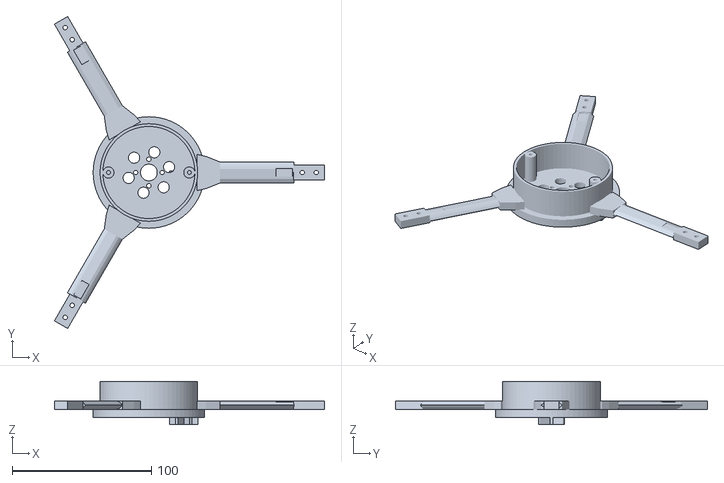
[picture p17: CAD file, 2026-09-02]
legado/Hologram_Orbiter_v2_1/exports/stl/01_aranha_ABS.stl
193.8 x 223.7 x 31.0

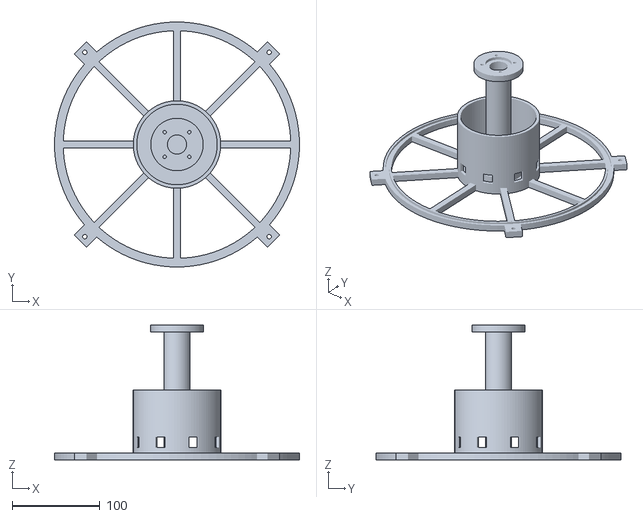
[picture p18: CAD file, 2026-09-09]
Hologram_Orbiter_v3_0/exports/stl/04_05_base_torre_ABS_integradas.stl
280.0 x 280.0 x 154.0

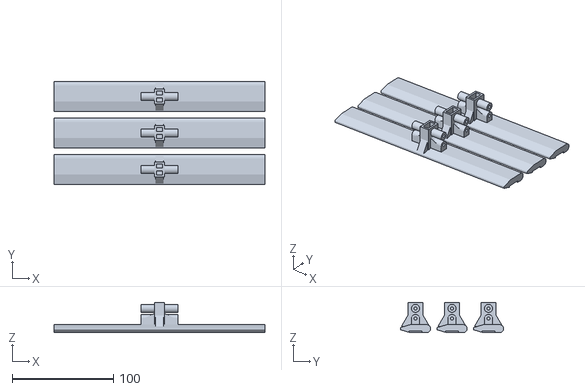
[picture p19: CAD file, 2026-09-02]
legado/Hologram_Orbiter_v2_1/exports/stl/02_painel_LED_ABS_3x_mesma_mesa.stl
208.0 x 102.0 x 30.0

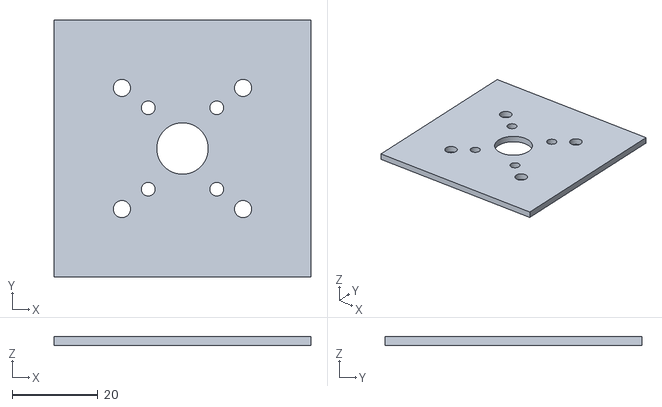
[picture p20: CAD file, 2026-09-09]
Hologram_Orbiter_v3_0/exports/stl/R01_suporte_motor_aluminio_NAO_IMPRIMIR.stl
60.0 x 60.0 x 2.00

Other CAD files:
legado/Hologram_Orbiter_v2_1/exports/stl/03_tampa_baia_ABS.stl
Hologram_Orbiter_v3_0/exports/stl/C02_cupom_canal_LED.stl
legado/Hologram_Orbiter_v2_1/exports/stl/08_anel_contencao_TPU_REFERENCIA.stl
Hologram_Orbiter_v3_0/exports/fonte/Hologram_Orbiter_v3_0.blend
legado/Hologram_Orbiter_v2_1/exports/fonte/Hologram_Orbiter_v2_1.blend
legado/Hologram_Orbiter_v2_1/exports/stl/04_05_base_torre_ABS_integradas.stl
legado/Hologram_Orbiter_v2_1/exports/stl/C02_cupom_canal_LED_13x1p8.stl
legado/Hologram_Orbiter_v2_1/exports/stl/R01_suporte_motor_aluminio_NAO_IMPRIMIR.stl

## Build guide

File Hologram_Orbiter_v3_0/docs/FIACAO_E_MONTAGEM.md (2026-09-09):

# Fiação, sensor de índice e montagem — Hologram Orbiter v3.0

Complementa a especificação (§6.3) com a rota física que o CAD implementa.
Cotas em mm; referenciais da spec §3. Atualizado para o cubo Ø92 e a baia
Ø82/Ø78 × 29 (regeneração de 03/09/2026).

## 1. Rota dos seis condutores por painel

Condutores por painel: 5 V e GND em AWG 24; DATA/CLK de entrada e de retorno em AWG 28. Chicote idêntico de seis condutores nos três painéis, com retorno do painel 3 sem conexão. Feixe estimado em 3,7 × 2,35 mm: medir a isolação e validar passagem real. A espiga **não é furada**: ela carrega os 158 N.

| Trecho | Peça | Feature no CAD | Cota |
|---|---|---|---|
| 1. Saída da baia | aranha | janela na parede do anel Ø82/Ø78, lado de fuga do braço, longe dos postes da tampa (que ficam em y = ±35) | r 38,5–42 · y −10…−5,5 · Z 0,8–5,8 |
| 2. Topo da raiz | aranha | bolso largo na face superior do alargamento da raiz | r 41,3–48 · y −10…0 · piso Z 2,3 |
| 3. Braço | aranha | sulco na face superior, lado de fuga | r 48–70 · y −4,4…0 · piso Z 2,3 (≈3 mm de profundidade) |
| 4. Ombro | — | os fios sobem 3 mm em ar livre nos 4 mm finais do braço e passam sobre o topo da luva (Z 5,1) | r 70–74 |
| 5. Entrada na carenagem | painel | janela no flanco plano da carenagem, acima da luva | y −7,4…−2,6 · z 5,4–10 (referencial do painel) |
| 6. Câmara traseira | painel | espaço livre atrás das torres, entre a alma central (y = 0) e a cauda | y < −1,2 |
| 7. Entrada na cavidade | painel | furo na parede interna da lâmina, ao lado da torre externa | y −6,2…−2,6 · z 6–9,5 |
| 8. Descida | painel | cavidade oca; cada diafragma tem um vão de 4 mm (y −1,5…2,5) | z +6 → −98,5 |
| 9. Saída para a fita | painel | bolso passante 8 × 3,5 mm abaixo do batente da fita | z −102…−98,3 |

A cunha de 45° sob a raiz do braço (r 46–53) fica **abaixo** do sulco: não
interfere na rota. Fixação dos fios no sulco: adesivo (CA ou epóxi) ou fita
Kapton. A força centrífuga puxa o feixe **ao longo** do sulco, não para fora dele.

**Montagem da fita.** Inserir a fita pelo topo do canal (aberto) e deslizar
até os ombros do bolso em Z = −98,5, com o adesivo do PCB colado no fundo do
canal de 12,4 × 2,0; os LEDs ficam rentes à face externa. Os pads de
entrada ficam na ponta inferior, para cima; soldar as quatro entradas, dobrar sobre
a ponta da fita e mergulhar no bolso. Passar o feixe pela cavidade com um guia
rígido de 1 mm a partir do furo do item 7 (gravidade ajuda: o painel fica de pé).

**CG e massa do painel.** A estimativa anterior usava 1,2 g de fios em uma rota de quatro condutores. Pesar os seis condutores, a fita e ferragens e medir a distribuição real antes de usar o momento parasita da junta. Os 42,1 g do relatório são um subtotal nominal, não confirmação da montagem completa.

O retorno DATA/CLK é soldado à ponta superior da fita e retorna à baia pela cavidade e abertura da lâmina. Prender durante a passagem com o acesso disponível; validar o processo em cupom/peça antes de montar. Não confundir quatro terminais de entrada da fita com o chicote completo de seis vias.

## 2. Sensor de índice angular

| Item | Onde | Cota |
|---|---|---|
| Sensor hall A3144 **nu** (TO-92, dessoldado do módulo HW-477 — 06-PENDENCIAS C1) | face inferior do cubo, face marcada (serigrafada) para baixo | r = 29, azimute **20°** do rotor (braço 1 = 0°) |
| Terminais | rasgo 4,8 × 1,4 subindo até a baia, debaixo da placa de interface (onde está o pull-up) | r ≈ 27,3–28,7, azimute 20° |
| Ímã Ø4 × 2 | topo do poste do `06_suporte_ima_ABS` | r = 29, azimute **20°** da base (+x = 0°) |
| Entreferro | | 2,5 mm (poste termina em Z = 177,5; Datum A em Z = 180) |
| Suporte | arco sob **dois** parafusos M4 da flange (r = 20, −45° e +45°), garfo aberto para dentro, braço radial até o poste | aba de 2,5 mm; poste de 21,5 mm sobre a chapa; arco a 4,6 mm da campânula |

**Fase:** o pulso ocorre quando o **braço 1 está alinhado com +x da base**
(sensor e ímã no mesmo azimute, 20°). Como o giro é anti-horário visto de cima,
o braço 1 passa pelo azimute 20° da base 1/18 de volta depois do pulso. Com dois
parafusos a aba não gira: a referência de fase não depende do aperto de um
único M4.

Os fios de fase do motor devem sair pelo lado **oposto** ao arco do suporte
(−x): o arco cobre 116° em torno de +x, a 2,5 mm de altura sobre a chapa.

O sensor alimenta o ESP32 do rotor diretamente (5 V, pull-up de 10 kΩ para
3,3 V). Nada de sinal cruzando o entreferro além do campo do ímã.

## 3. Fixação do rotor no eixo

O desenho do motor mostra um **colar Ø8 × 5 mm** sob a rosca (7 mm acima da
campânula se o ressalto de 2 mm existir). O cubo tem 6 mm: o colar termina
acima do fundo de qualquer rebaixo, e uma arruela M6 assentaria no aço do
colar — a porca apertaria o colar, não o cubo. Daí a pilha abaixo, válida nas
duas leituras do desenho.

1. O cubo desce pelo colar (furo Ø8 H8) e assenta nos raios da campânula.
2. **Arruela Ø20 × Ø8,5 × 2 mm em alumínio** (cortada da chapa da R01; o furo
   passa pelo colar) direto no topo do cubo, sem rebaixo. 1,9 MPa no ABS a
   0,6 N·m.
3. **Porca M6 fina DIN 439B (3 mm) com Loctite 243**, a 0,6 N·m. **Não usar a
   porca cônica nem a autotravante baixa de 6 mm**: com a rosca acabando em
   12–14 mm, a de 6 mm terminaria no fim do eixo.
4. Pilha sobre o topo do cubo: arruela 0–2, porca 2–5, ponta do eixo em +8 (ou
   +6 na leitura de 12 mm). Os trilhos do berço ficam em Z = +9, a bateria em
   Z = 9…26 dentro dos 29 mm da baia.
5. Furos de provisão 4 × Ø3,2 em PCD 19 ficam sob a arruela: só servem com
   adaptador de hélice e com a arruela removida.

**Antes de comprar a porca, medir no motor**, a partir da face em que o cubo
assenta: altura do topo do colar e da ponta do eixo.

## 4. Sequência de montagem do rotor

1. Confirmar Hall em bancada: VCC=5 V, pull-up de 10 kΩ para 3,3 V, face marcada voltada ao ímã. Testar polaridade/entreferro/campo do motor antes de colar. Montar o sensor no bolso inferior e passar os terminais pelo rasgo.
2. Preparar os chicotes idênticos de seis condutores e os painéis; validar continuidade, isolamento e massa. Passar entrada/retorno pelos canais, sem furar a espiga. Parafusar os painéis com 2 × M3 × 40 e porcas capturadas.
3. Posicionar a eletrônica conforme `spider.bay_layout`: interface em +x, ESP32 em −x, capacitor em (22,5; −22), buck a 140° com folga de parede de 1,5 mm. O envelope/guia recua 1,2 mm em relação à revisão anterior. Conferir o módulo real e fixar; manter a bateria fora do berço por enquanto.
4. Fazer a correção estática inicial enquanto os alívios inferiores estão acessíveis. Usar os contrapesos calculados no relatório atual como ponto inicial, ajustando às massas reais. Registrar posições; a correção em dois planos exige o método instrumentado do bloqueador C.
5. Montar o cubo no eixo, assentar a arruela Ø20 × Ø8,5 × 2 e apertar a porca fina M6 conforme §3. **A bateria e a tampa ainda devem estar removidas**, para acesso axial à porca. Conferir eixo, rosca, giro livre e entreferro.
6. Instalar, reter e conectar a bateria no berço em Z local 9…26 (global 195…212). Conferir proteção elétrica, chave, fios afastados do eixo e retenção de todos os componentes.
7. Fechar a tampa com 2 × M3 autoatarraxantes nos postes y=±35. Pesar e reconciliar o conjunto completo; repetir o balanceamento após qualquer abertura, correção ou troca de componente.
8. Operação somente após resolver as pendências estruturais e instrumentais. Ensaio com contenção, base grampeada e operação remota; rampa nominal de RPM ≥12 s, limites e bloqueadores conforme plano 04.

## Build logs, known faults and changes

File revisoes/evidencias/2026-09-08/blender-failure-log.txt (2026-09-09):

BlenderMCP: cannot start server in background mode (blender -b) - commands would never execute
BlenderMCP: run Blender with a GUI, or use a virtual display: xvfb-run -a blender
BlenderMCP addon registered
BlenderMCP server stopped
BlenderMCP addon unregistered
Blender 5.2.1 LTS (hash 9e2066aef7ef built 2026-09-01 00:24:57)

Blender quit
Traceback (most recent call last):
  File "/tmp/orbiter-cad-audit-caeum7wg/fail.py", line 1, in <module>
    raise RuntimeError('ORBITER_AUDIT_EXPECTED_FAILURE')
RuntimeError: ORBITER_AUDIT_EXPECTED_FAILURE

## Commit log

2026-09-02 Hologram Orbiter v3.0 — documentação, CAD e eletrônica
    Display volumétrico por persistência de visão: 3 painéis de LEDs girando a
    1800 RPM formam uma imagem cilíndrica de Ø208 × 201 mm a 90 Hz.
    Conteúdo:
    - Documentação v3.0: especificação CAD, plano de projeto, lista de
    componentes, plano de ensaios e esquema elétrico do rotor.
    - Auditoria da v2.1: 24 não conformidades com recálculo independente de
    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
    [01_aranha_ABS.stl, 02_painel_LED_ABS_1x.stl, 02_painel_LED_ABS_3x_mesma_mesa.stl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]
2026-09-02 Revisão independente e correções verificadas
    Adiciona 06-REVISAO-INDEPENDENTE-v3.0.md e aplica as correções que se
    sustentaram na verificação. Cada alegação foi refeita por conta própria
    antes de ser aceita.
    Confirmadas e aplicadas:
    - Divisor do ADC 100k/56k dava 3,02 V em 8,4 V, fora da faixa linear do
    ESP32-C3 (~2,5 V a 12 dB). Corrigido para 150k/47k → 2,00 V.
    - Parafuso do painel: torre de 36 mm com porca no fundo exige M3 × 40,
    não × 20. Bolso de 2,8 mm aceita porca plana (2,4), não nyloc (4,0):
    passa a porca plana + trava química.
    - Motor → chapa: M3 × 6, não × 8. M3 × 8 penetra 6 mm numa base que
    aceita ~4–5 antes de tocar o enrolamento.
    - "Fadiga a 1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
2026-09-02 Apoio da base: critério de contato em vez de planeza, e abas de grampo
    Decisão: manter a base monolítica com apoio pleno. Três pés seriam um
    caminho de carga pior — hoje a carga da torre desce pelo piso da baia
    direto para a mesa e as nervuras ficam respaldadas; sobre pés o caminho
    passaria a torre -> piso -> nervura -> pé, e a nervura de 8 x 8 mm num
    vão de 90 mm dá 2,8 N/mm contra os ~66 exigidos para um modo de balanço
    em 60 Hz.
    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
2026-09-02 Campânula deixa de ser bloqueador: o cubo já traz os dois caminhos
    Verificado no STL da aranha: a face inferior do cubo tem 4 x Ø3,20 em
    PCD 19 (a 45°) além do furo central Ø8. Os dois caminhos de fixação —
    eixo M6 com porca baixa, ou parafusos num adaptador de hélice — já estão
    na geometria, então a medição da campânula não trava CAD nem impressão.
    Ela decide o fixador na montagem, e com ele o risco de fluência do
    aperto M6 sobre ABS (~40 MPa sob a arruela). Rebaixada de P0 para item
    de pré-montagem na Fase 2.
    Também estava errado ligá-la à altura da baia: com o pack de
    55 x 30 x 13 a conta é 5,6 + 13 = 18,6 <= 20, cabe com a porca no lugar.
    Os 5,6 mm só import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
2026-09-02 Revisão vira lista de pendências; invólucro e campânula fora de escopo
    A revisão de 02/09 não estava resolvida — restavam 2 P0 de malha, 6
    itens de CAD, 4 de eletrônica, 3 de medição e 7 documentais. Substituída
    por 06-PENDENCIAS-ABERTAS-v3.0.md, que cobre só o que falta; o que foi
    resolvido sai do documento e fica no histórico.
    Invólucro removido do escopo: seção 5.8 da especificação, seção 5 da
    lista de componentes, linhas de status do README e do plano, e as
    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
2026-09-02 Fita medida em 2,0 mm: canal vai a 2,2 com parede local de 3,0
    A medição de 02/09 dá 12,0 x 2,0 mm, não 12,0 x 1,0 como registrado. O
    canal de 1,2 mm deixaria a fita 0,8 mm saliente (+12 mN.m, +1,1 A, +9 C
    no motor) e um canal de 2,2 numa parede de 2,0 romperia a cavidade.
    Solução: recuar a cavidade de x=2,0 para x=1,0 apenas na faixa de
    12,4 mm do canal. Parede local de 3,0 mm, piso de 0,8 mm mantido, perfil
    aerodinâmico intacto, +2,7 g por painel. Painel montado vai a 44,5 g,
    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
2026-09-02 Cupom C02 e caso de carga alinhados ao canal de 2,2 mm
    O cupom de calibração do canal passa a 12,4 x 2,2 e o painel real chega
    aos 44,5 g que a carga de projeto já assumia — a margem de 6% que
    existia enquanto o painel pesava 41,87 g deixa de existir.
2026-09-02 Canal em degrau e baia ampliada
    Fita: a imagem mostra PCB fino com encapsulamento 5050 de 1,6 mm. Em vez
    do canal reto de 2,2 que eu havia proposto, canal em degrau — 12,4 x 0,6
    para o PCB, rasgo de 5,4 x 1,4 para os LEDs, parede local de 2,8 só sob
    o rasgo. Custa 0,9 g por painel contra 2,7, e a ponte de 0,8 mm vence
    5,4 mm em vez de 12,4. O PCB apoia nos ombros, onde o adesivo trabalha.
    Baia: cubo Ø80 -> Ø92, baia Ø82/Ø78 x 26. Altura útil de 14,4 para
    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
2026-09-02 Glossário, premissas e sincronia final da sessão
    Acrescenta 07-GLOSSARIO-E-PREMISSAS.md com o vocabulário do projeto —
    campânula, espiga, boss, enrolamento, fluência, coletor aberto — e, mais
    importante, a tabela de o que foi medido, o que foi derivado e o que
    ainda é assumido.
    Três itens em negrito nessa tabela são o caso térmico inteiro: Rth de
    3,5 C/W, Cd da lâmina de 0,35 e A.Cd do boss de 350 mm2. Todos
    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
2026-09-02 Memória de cálculo alinhada ao canal em degrau
    O painel nu volta a partir do valor medido no STL (31,67 g) mais os
    0,9 g da parede local do degrau, dando ~42,8 g montado. Os 34,2 g eram
    do canal reto de 2,2, proposta superada.
    A carga de projeto continua nos 44,5 g do teto do limite, agora com a
    folga de 4% explícita.
2026-09-02 Componentes reais: datasheets consultados, tres divergencias corrigidas
    Modelos adicionados ao glossario, verificados contra datasheet.
    NAO CONDIZ, corrigido:
    - Altura do conjunto motor de 38 mm nao e a cota da cadeia em Z. O cubo
    desliza no eixo, nao apoia nele: chapa -> Datum B = 24 do corpo + 6 do
    cubo = 30 mm. Os 38 mm sao altura total do componente, e com o eixo em
    12 mm seriam 36. Linha desdobrada em duas.
    - ESC listado como 20A com 15 A no corpo da linha. E 20 A continuo,
    25 A de pico.
    NAO FUNCIONA como esta:
    - Modulo hall HW-477 no rotor. Tem pull-up proprio: em 5 V a saida vai a
    5 V e queima a entrada do ESP32-C3, que nao tolera. E 1,5-2,5 g a
    r=29 mm valem 43-72 g.mm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
    [01_aranha_ABS.stl, 02_painel_LED_ABS_1x.stl, 02_painel_LED_ABS_3x_mesma_mesa.stl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]
2026-09-02 Parte fixa documentada; sensor nu; gerador de sinal encerrado
    O documento 05 cobria so o rotor. Acrescenta a secao 8 com a cadeia
    fixa: fonte, ESC, motor e o gerador do sinal de acelerador, mais a
    sequencia de armacao, os requisitos de rampa e parada, e a configuracao
    do ESC antes de girar.
    Gerador de sinal: ha Arduino e gerador de bancada em maos. O Arduino e o
    certo, porque a rampa de 8 s e a funcao que importa e o gerador de
    bancada nao a faz bem. Pendencia C1 encerrada.
    Tres armadilhas registradas: GND comum entre Arduino, ESC e fonte;
    alimentacao unica; e nao cortar a energia com o rotor girando.
    Glossario: a placa HW-477 sai. Fica o A3144 nu, com o motivo escrito —
    pull-up proprio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
    [01_aranha_ABS.stl, 02_painel_LED_ABS_1x.stl, 02_painel_LED_ABS_3x_mesma_mesa.stl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]
2026-09-03 CAD v3.0.2: canal do LED unico, fixacao do eixo pelo colar, layout da baia, higiene documental; auditoria v2.1 arquivada
    [01_aranha_ABS.stl, 02_painel_LED_ABS_1x.stl, 02_painel_LED_ABS_3x_mesma_mesa.stl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]
2026-09-03 CAD v3.0.3: revisao independente aplicada, tres colisoes de montagem corrigidas
    Revisao externa de 03/09 sobre os documentos 01-07 e o pacote CAD, com
    recalculo do §10 e sondagem por raios nas malhas. Incorporada ao 06 (tabela
    de disposicao dos 30 achados); o documento 08 solto foi apagado.
    Tres colisoes de montagem que nenhum dos 51 criterios cobria, confirmadas na
    malha e corrigidas no CAD:
    - ponta do eixo M6 entrava 2 mm no envelope da bateria (trilhos Z 6 -> 9,
    baia 26 -> 29; vale nas duas leituras do desenho, 14 e 12 mm)
    - trilhos do berco invadiam 0,5 mm o assento da arruela O20
    (rail_x_positions +-11 -> +-12)
    - cabecas dos 4 x M3 do motor assentavam na face da flange, deixando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
    [01_aranha_ABS.stl, 04_05_base_torre_ABS_integradas.stl, Hologram_Orbiter_v3_0.blend]
2026-09-03 Ratificacoes de 03/09: B'3 fechada, polaridade do ima definida, C9 recortada
    B'3 fechada. Pedro ratificou o canal unico 12,4 x 2,0 no lugar do canal em
    degrau da spec §5.1: os LEDs ficam em cima do PCB e o degrau so funcionaria com
    a fita de cabeca para baixo. Sai de Abertas, entra na tabela de fechadas.
    C2 decidida, com ressalva. Face positiva do ima aponta para o sensor
    (repulsao), registrado em unverified_interfaces.magnet.polarity. Fica marcada
    polarity_bench_confirmed = false porque as duas convencoes em jogo se
    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
    [Hologram_Orbiter_v3_0.blend]
2026-09-03 Documentos alinhados a revisao 3.0.3: massa, baia, trilhos e contrapeso
    A revisao 3.0.3 mudou massa do rotor, altura da baia, posicao dos trilhos e
    contrapeso, mas so a lista de pendencias e o gerador acompanharam. Catorze
    arquivos seguiam publicando os numeros da 3.0.2, entre eles o README e o
    relatorio de validacao, que descrevia uma malha diferente da que esta no STL.
    Rotor de 274,3 para 278,6 g e folga de 5,7 para 1,4 g. Aranha de 67,5 para
    71,0 e base de 321,3 para 319,8. Baia de 26 para 29 mm e trilhos de Z=6 para
    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
2026-09-03 Revisao das ratificacoes de 03/09 arquivada em revisoes/
    Revisao independente do pacote na 3.0.3, depois de B'3, C2 e C9. Validador de
    malhas rodado do zero: 9 de 9 STL passam e o resultado coincide campo a campo
    com o relatorio versionado. Massas e balanceamento recalculados a mao batem com
    o relatorio de aceitacao. As tres ratificacoes se sustentam; o defeito era de
    propagacao, corrigido no commit anterior.
    Diretorio novo, com LEIA-ME no padrao do legado/. O LEIA-ME registra que uma
    revisao nao manda em cota nem em requisito: a hierarquia do README continua
    valendo e o que falta continua na 06. Nome com data ISO porque revisoes se
    acumulam; a faixa 01 a 07 fica reservada ao conjunto vivo.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
2026-09-08 proposta de projeto de extensao conforme o solicitado pelo edital 2024/2025, contendo a proposta em PDF, o código para gerar as figuras e os arquivos de figuras utilizados no documento.
2026-09-09 Corrige calculos, montagem e validacao CAD na revisao 3.0.4
    Recalcula flexao, acionamento e massa; corrige a folga do buck, os parametros de encaixe e as instrucoes eletricas e mecanicas. Regenera o modelo Blender, os STLs e as visualizacoes, com relatorios e evidencias da auditoria.
    Torna o build transacional, valida inventario e propagacao de parametros e preserva as restricoes de fabricacao e operacao ainda dependentes de ensaios fisicos.
    Validacao: 16 testes aprovados, 56 criterios geometricos atendidos e 9 STLs validados.
    [01_aranha_ABS.stl, 02_painel_LED_ABS_1x.stl, 02_painel_LED_ABS_3x_mesma_mesa.stl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]
2026-09-14 fix: sobreposição de braços e furação dos fios da led
    [01_aranha_ABS.stl, Hologram_Orbiter_v3_0.blend]
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2026-09-21 fix: retirada de foto no último slide
2026-09-21 Corrige a fiação dos painéis no 01 e acrescenta pull-downs no 05
    - 01 §6.3: os seis condutores são 5 V e GND, CLK e DATA de entrada e CLK
    e DATA de retorno da cadeia. O texto de 482264a falava em DATA e CLK com
    retorno GND, o que não deixa fio para encadear as fitas; o 05 §4, a
    FIACAO §1 e o item R09 da revisão de 08/09 já diziam o certo.
    - 05 §2.2: pull-down de 10 kΩ ao GND nas entradas de CLK e DATA do
    74AHCT125. No reset, o GPIO 4 e o GPIO 6 ficam só como entrada, sem pull,
    e a fita poderia receber lixo e acender antes do limite de corrente do
    firmware. Tabela de pinos, placa de interface (§7) e lista 03 alinhadas.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
2026-10-30 Firmware v0.3.0 com perfil linear/overshoot e partida serial; registro da falha R02 e unificação da fonte
    - Firmware (controle-motor / esp32-base v0.3.0):
    * Perfil de partida linear como padrão (subida contínua ao alvo sem chute nem overshoot);
    * Perfil overshoot selecionável via serial ('o'), restaurável para linear ('l');
    * Comando de partida via serial ('g') além do botão físico D32, com intertravamento de segurança;
    * 34 testes unitários cobrindo transições de estado, intertravamento e console.
    - Documentação e Segurança:
    * Registro da pendência crítica R02 em 06-PENDENCIAS-ABERTAS e relato em revisoes/
    após relato de ruptura da raiz de braço da aranha d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
